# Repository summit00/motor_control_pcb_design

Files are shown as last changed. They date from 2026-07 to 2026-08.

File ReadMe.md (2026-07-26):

# STM32H563 BLDC Motor Controller

A three-phase BLDC/PMSM motor controller designed for high-performance Field-Oriented Control (FOC).

## Features

- STM32H563 microcontroller
- DRV8353 three-phase gate driver
- Three low-side current shunts
- Up to 60 V DC bus
- CAN interface
- USB-C interface
- Incremental encoder interface

## Repository Structure

```
.
├── motor_bldc_esc_V1.kicad_pro
├── motor_bldc_esc_V1.kicad_sch
├── motor_bldc_esc_V1.kicad_pcb
├── powerstage.kicad_sch
├── power.kicad_sch
├── mcu.kicad_sch
├── communication.kicad_sch
└── encoder.kicad_sch
```

## Status

🚧 Work in progress.

The hardware is currently under development and has not yet been validated on physical hardware.

## License

Hardware released under the CERN Open Hardware License.

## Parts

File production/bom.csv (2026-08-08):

Designator | Footprint | Quantity | Value | LCSC Part #
C1, C11, C12, C14, C16, C17, C18, C19, C20, C21, C22, C34, C4, C50 | 0603 | 14 | 100n | C14663
C10, C8, C9 | 0805 | 3 | 1u | C5370002
C13, C15 | 0603 | 2 | 33p | https://jlcpcb.com/partdetail/2015-CL10C330JB8NNNC/C1663
C2 | 1210 | 1 | 10u | C5156756
C23, C24, C25, C35, C49 | 0603 | 5 | 2u2 | C23630
C26, C27, C29, C38, C5 | 0805 | 5 | 100n | C28233
C28, C33, C43, C47 | 1210 | 4 | 4.7u | C381466
C3 | 0603 | 1 | 220p | C1603
C30, C44, C45, C46 | 0603 | 4 | 1u | C15849
C36, C39, C40, C41, C42 | 0805 | 5 | 10u | C15850
C37, C48 | 0603 | 2 | 2n2 | C1604
C6 | 0805 | 1 | 47n | C53134
C7 | 0805 | 1 | 1u | C28323
D4 | SOT-23 | 1 | PESD1CAN,215 | C15771
D5 | 0805 | 1 | LED_Status | C84256
D6 | 0805 | 1 | LED_Error | C84256
D7 | 0805 | 1 | LED_5V | C84256
D8 | 0805 | 1 | LED_3V3 | C84256
FB1 | 0805 | 1 | 60 | C845118
FB2 | 0603 | 1 | 120 | C14709
J6 | USB_C_Receptacle_G-Switch_GT-USB-7010ASV | 1 | USB_C_Receptacle_USB2.0_16P | C2988369
L1 | L_Sunlord_SWPA8040S | 1 | 39u | C206289
Q1, Q2, Q3, Q4, Q5, Q6 | TDSON-8-1 | 6 | BSC060N10NS3G | C501504
R1 | 0603 | 1 | 4k7 | C23162
R10 | 0805 | 1 | 200k | C17539
R11 | 0603 | 1 | 30k | C22984
R12 | 0805 | 1 | 100k | C149504
R13 | 0805 | 1 | 3k3 | C26010
R15 | 0603 | 1 | 47k | C25819
R16 | 0805 | 1 | 150 | C17471
R17, R30, R31 | 0603 | 3 | 330 | C23138
R18, R19 | 0603 | 2 | 5k1 | C23189
R2, R32, R33, R35 | 0805 | 4 | 10k | C17414
R20 | 0603 | 1 | 120 | C22787
R21 | 0603 | 1 | 68k | C23231
R22, R23, R24, R25, R26, R27 | 0603 | 6 | 2 | C22977
R28, R29 | 0603 | 2 | 100k | C25803
R34 | 0603 | 1 | 150k | C22807
R6, R7, R8 | 0805 | 3 | 120 | C17437
R9 | 0805 | 1 | 1M | C17514
U1 | DRV8353SRTAT | 1 | DRV8353SRTAT | C2150480
U3 | SOIC-16_3.9x9.9mm_P1.27mm | 1 | AM26LV32xD | C527448
U4 | SOT-23-5 | 1 | TLV75533PDBVR | C404027
U5 | LM5164DDAR | 1 | TI LM5164DDAR | C477928
U6 | SOT-23-6 | 1 | USBLC6-2SC6 | C7519
U7 | SOIC-8_3.9x4.9mm_P1.27mm | 1 | SN65HVD230DR | C12084
U8 | LQFP-100_14x14mm_P0.5mm | 1 | STM32H523VET6 | C27338462
Y1 | Crystal_SMD_5032-2Pin_5.0x3.2mm_HandSoldering | 1 | Crystal | C115962

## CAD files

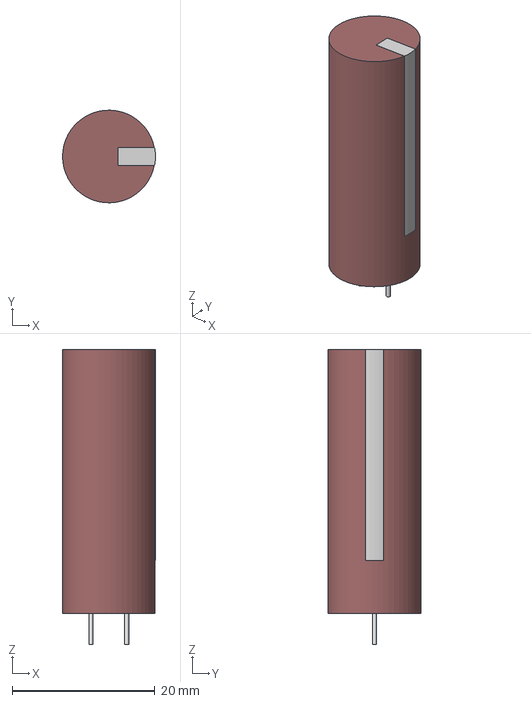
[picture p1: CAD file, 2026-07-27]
3dModels/100ZLJ330M12.5X35.step
13.0 x 13.0 x 41.4 mm

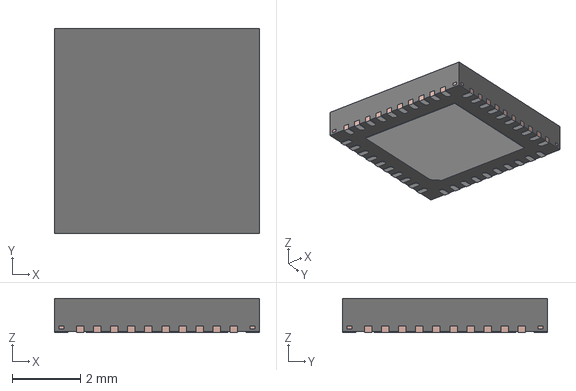
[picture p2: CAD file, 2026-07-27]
3dModels/DRV8353SRTAT.stp
6.00 x 6.00 x 1.00 mm
FRAME

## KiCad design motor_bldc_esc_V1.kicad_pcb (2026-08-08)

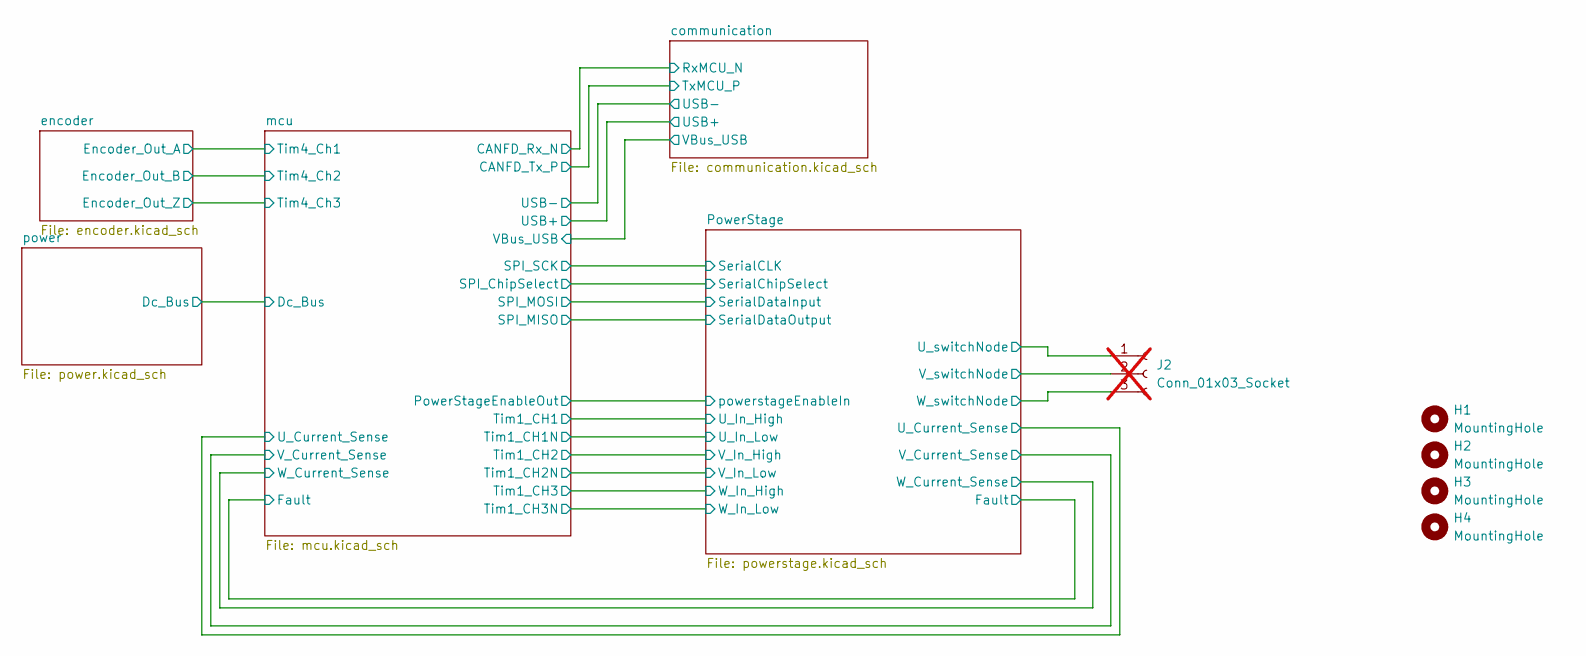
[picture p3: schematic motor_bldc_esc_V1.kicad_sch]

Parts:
H1, H2, H3, H4: MountingHole; MountingHole_3.2mm_M3
J2: Conn_01x03_Socket; SolderWire-4sqmm_1x03_P12mm_D3mm_OD6mm; not fitted

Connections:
/PowerStage/U_switchNode: J2.1; also elsewhere on the board
/PowerStage/V_switchNode: J2.2; also elsewhere on the board
/PowerStage/W_switchNode: J2.3; also elsewhere on the board

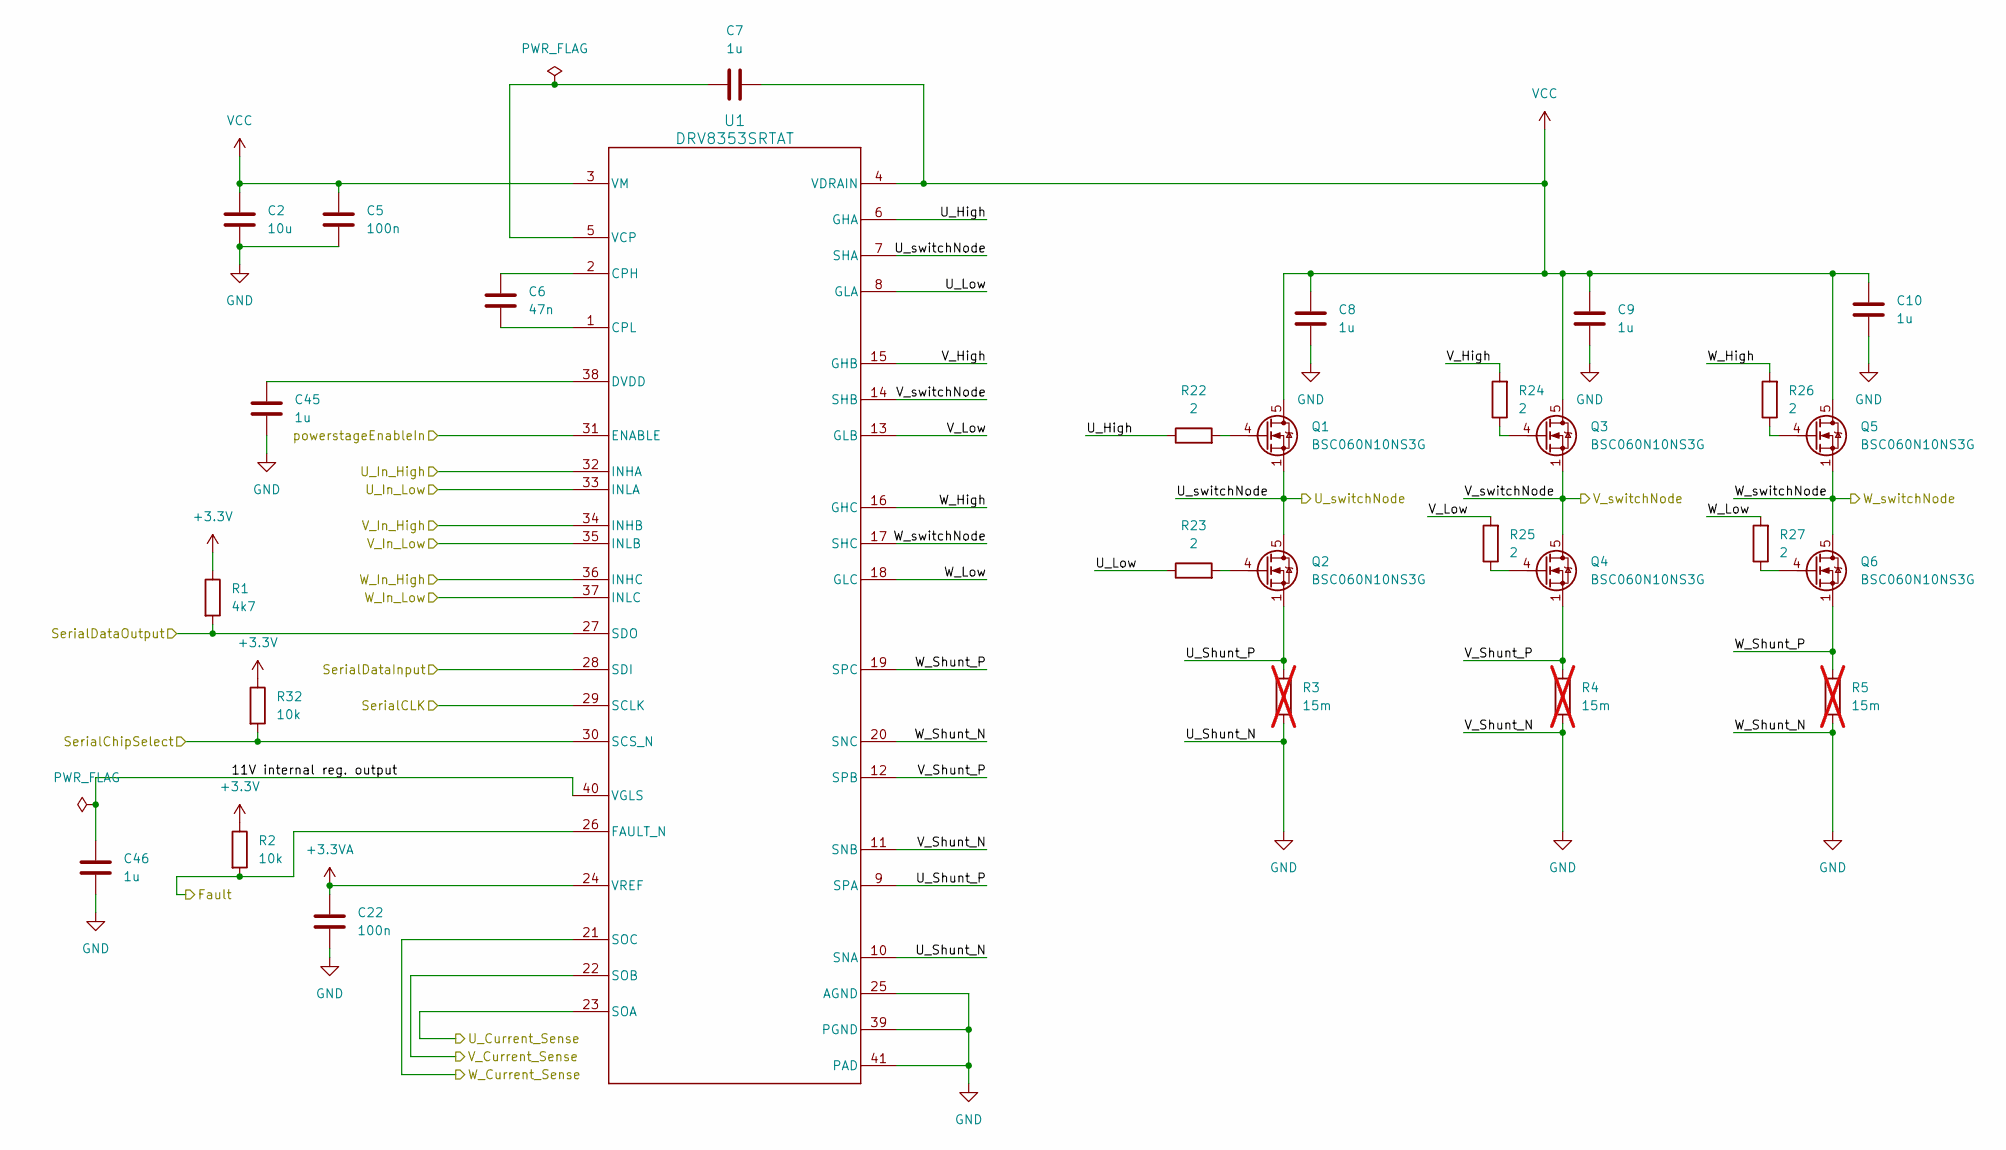
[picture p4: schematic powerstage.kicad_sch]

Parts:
C2: 10u; C_1210_3225Metric_Pad1.33x2.70mm_HandSolder; LCSC C5156756
C5: 100n; C_0805_2012Metric_Pad1.18x1.45mm_HandSolder; LCSC Part # C28233
C6: 47n; C_0805_2012Metric_Pad1.18x1.45mm_HandSolder; LCSC Part # C53134
C7: 1u; C_0805_2012Metric_Pad1.18x1.45mm_HandSolder; LCSC Part # C28323
C8, C9, C10: 1u; C_0805_2012Metric_Pad1.18x1.45mm_HandSolder; LCSC Part # C5370002
C22: 100n; C_0603_1608Metric; LCSC Part # C14663
C45, C46: 1u; C_0603_1608Metric; LCSC Part # C15849
Q1, Q2, Q3, Q4, Q5, Q6: BSC060N10NS3G; TDSON-8-1; LCSC Part # C501504
R1: 4k7; R_0603_1608Metric; LCSC Part # C23162
R2, R32: 10k; R_0805_2012Metric_Pad1.20x1.40mm_HandSolder; LCSC Part # C17414
R3, R4, R5: 15m; R_2512_6332Metric_Pad1.40x3.35mm_HandSolder; LCSC C7420045; not fitted
R22, R23, R24, R25, R26, R27: 2; R_0603_1608Metric; LCSC Part # C22977
U1: DRV8353SRTAT; LCSC Part # C2150480

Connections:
+3.3V: R1.1, R2.1, R32.1; also elsewhere on the board
+3.3VA: C22.1, U1.24 (VREF); also elsewhere on the board
/PowerStage/11V internal reg. output: C46.1, U1.40 (VGLS)
/PowerStage/Fault: R2.2, U1.26 (FAULT_N); also elsewhere on the board
/PowerStage/SerialCLK: U1.29 (SCLK); also elsewhere on the board
/PowerStage/SerialChipSelect: R32.2, U1.30 (SCS_N); also elsewhere on the board
/PowerStage/SerialDataInput: U1.28 (SDI); also elsewhere on the board
/PowerStage/SerialDataOutput: R1.2, U1.27 (SDO); also elsewhere on the board
/PowerStage/U_Current_Sense: U1.23 (SOA); also elsewhere on the board
/PowerStage/U_High: R22.1, U1.6 (GHA)
/PowerStage/U_In_High: U1.32 (INHA); also elsewhere on the board
/PowerStage/U_In_Low: U1.33 (INLA); also elsewhere on the board
/PowerStage/U_Low: R23.1, U1.8 (GLA)
/PowerStage/U_Shunt_P: Q2.1 (S), Q2.2 (S), Q2.3 (S), R3.1, U1.9 (SPA)
/PowerStage/U_switchNode: Q1.1 (S), Q1.2 (S), Q1.3 (S), Q2.5 (D), U1.7 (SHA); also elsewhere on the board
/PowerStage/V_Current_Sense: U1.22 (SOB); also elsewhere on the board
/PowerStage/V_High: R24.2, U1.15 (GHB)
/PowerStage/V_In_High: U1.34 (INHB); also elsewhere on the board
/PowerStage/V_In_Low: U1.35 (INLB); also elsewhere on the board
/PowerStage/V_Low: R25.2, U1.13 (GLB)
/PowerStage/V_Shunt_P: Q4.1 (S), Q4.2 (S), Q4.3 (S), R4.1, U1.12 (SPB)
/PowerStage/V_switchNode: Q3.1 (S), Q3.2 (S), Q3.3 (S), Q4.5 (D), U1.14 (SHB); also elsewhere on the board
/PowerStage/W_Current_Sense: U1.21 (SOC); also elsewhere on the board
/PowerStage/W_High: R26.2, U1.16 (GHC)
/PowerStage/W_In_High: U1.36 (INHC); also elsewhere on the board
/PowerStage/W_In_Low: U1.37 (INLC); also elsewhere on the board
/PowerStage/W_Low: R27.2, U1.18 (GLC)
/PowerStage/W_Shunt_P: Q6.1 (S), Q6.2 (S), Q6.3 (S), R5.1, U1.19 (SPC)
/PowerStage/W_switchNode: Q5.1 (S), Q5.2 (S), Q5.3 (S), Q6.5 (D), U1.17 (SHC); also elsewhere on the board
/PowerStage/powerstageEnableIn: U1.31 (ENABLE); also elsewhere on the board
GND: C2.2, C5.1, C8.2, C9.2, C10.2, C22.2, C45.2, C46.2, R3.2, R4.2, R5.2, U1.10 (SNA), U1.11 (SNB), U1.20 (SNC), U1.25 (AGND), U1.39 (PGND), U1.41 (PAD); also elsewhere on the board
unnamed: Q1.4 (G), R22.2
unnamed: Q2.4 (G), R23.2
unnamed: Q3.4 (G), R24.1
unnamed: Q4.4 (G), R25.1
unnamed: Q5.4 (G), R26.1
unnamed: Q6.4 (G), R27.1
unnamed: C6.2, U1.2 (CPH)
unnamed: C6.1, U1.1 (CPL)
unnamed: C45.1, U1.38 (DVDD)
unnamed: C7.1, U1.5 (VCP)
VCC: C2.1, C5.2, C7.2, C8.1, C9.1, C10.1, Q1.5 (D), Q3.5 (D), Q5.5 (D), U1.3 (VM), U1.4 (VDRAIN); also elsewhere on the board

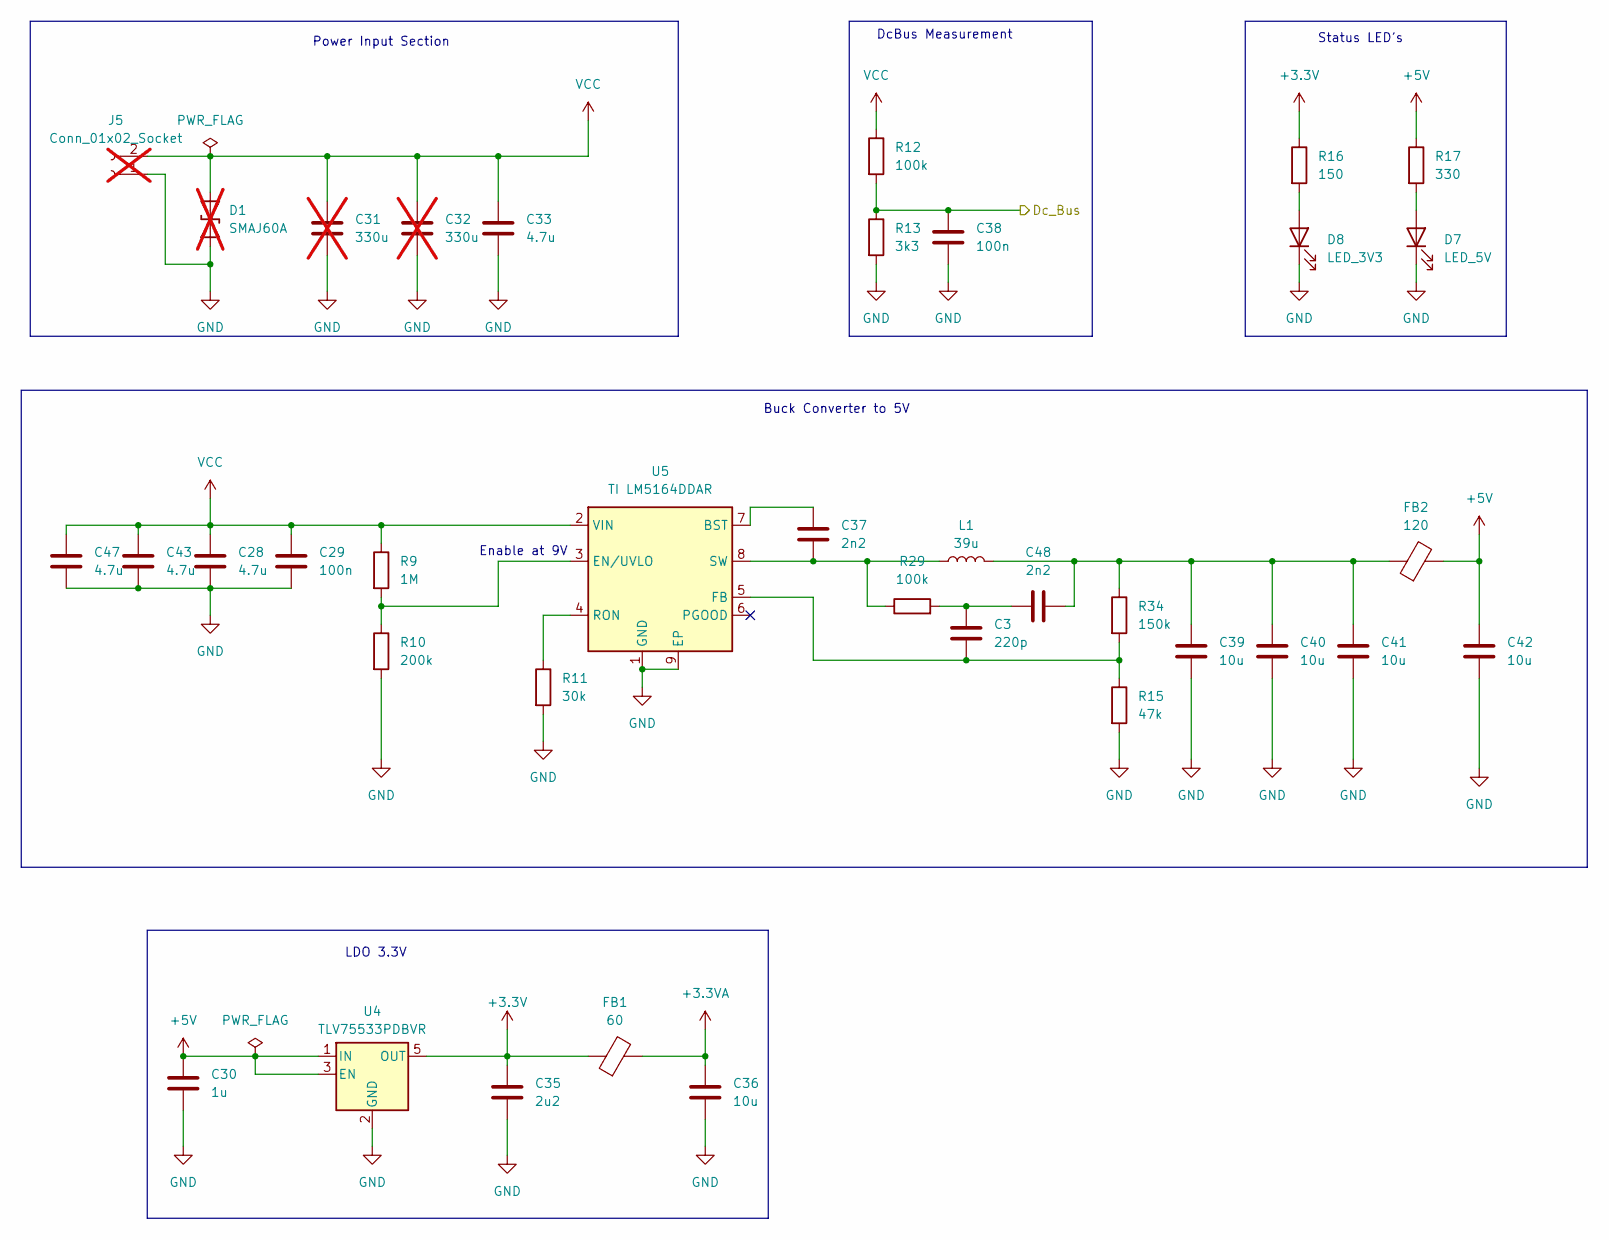
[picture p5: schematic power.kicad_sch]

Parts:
C3: 220p; C_0603_1608Metric; LCSC Part # C1603
C28, C33, C43, C47: 4.7u; C_1210_3225Metric_Pad1.33x2.70mm_HandSolder; LCSC C381466
C29, C38: 100n; C_0805_2012Metric_Pad1.18x1.45mm_HandSolder; LCSC Part # C28233
C30: 1u; C_0603_1608Metric; LCSC Part # C15849
C31, C32: 330u; 100ZLJ330M12.5X35; not fitted
C35: 2u2; C_0603_1608Metric; LCSC Part # C23630
C36, C39, C40, C41, C42: 10u; R_0805_2012Metric_Pad1.20x1.40mm_HandSolder; LCSC Part # C15850
C37, C48: 2n2; C_0603_1608Metric; LCSC Part # C1604
D1: SMAJ60A; D_SMA-SMB_Universal_Handsoldering; not fitted
D7: LED_5V; LED_0805_2012Metric; LCSC C84256
D8: LED_3V3; LED_0805_2012Metric; LCSC C84256
FB1: 60; L_0805_2012Metric_Pad1.05x1.20mm_HandSolder; LCSC Part # C845118
FB2: 120; L_0603_1608Metric_Pad1.05x0.95mm_HandSolder; LCSC Part # C14709
J5: Conn_01x02_Socket; SolderWire-4sqmm_1x02_P12mm_D3mm_OD6mm; not fitted
L1: 39u; L_Sunlord_SWPA8040S; LCSC Part # C206289
R9: 1M; R_0805_2012Metric; LCSC Part # C17514
R10: 200k; R_0805_2012Metric; LCSC Part # C17539
R11: 30k; R_0603_1608Metric; LCSC C22984
R12: 100k; R_0805_2012Metric_Pad1.20x1.40mm_HandSolder; LCSC Part # C149504
R13: 3k3; R_0805_2012Metric_Pad1.20x1.40mm_HandSolder; LCSC Part # C26010
R15: 47k; R_0603_1608Metric; LCSC Part # C25819
R16: 150; R_0805_2012Metric_Pad1.20x1.40mm_HandSolder; LCSC Part # C17471
R17: 330; R_0603_1608Metric; LCSC Part # C23138
R29: 100k; R_0603_1608Metric; LCSC Part # C25803
R34: 150k; R_0603_1608Metric; LCSC Part # C22807
U4: TLV75533PDBVR; SOT-23-5; LCSC Part # C404027
U5: TI LM5164DDAR; LM5164DDAR; LCSC Part # C477928

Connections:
+3.3V: C35.1, FB1.1, R16.1, U4.5 (OUT); also elsewhere on the board
+3.3VA: C36.1, FB1.2; also elsewhere on the board
+5V: C30.1, C42.1, FB2.2, R17.1, U4.1 (IN), U4.3 (EN); also elsewhere on the board
/mcu/Dc_Bus: C38.2, R12.2, R13.1; also elsewhere on the board
GND: C28.2, C29.1, C30.2, C31.2, C32.2, C33.2, C35.2, C36.2, C38.1, C39.2, C40.2, C41.2, C42.2, C43.2, C47.2, D1.1 (A1), D7.1 (K), D8.1 (K), J5.1, R10.2, R11.2, R13.2, R15.2, U4.2 (GND), U5.1 (GND), U5.9 (EP); also elsewhere on the board
unnamed: C3.1, C48.1, R29.2
unnamed: C39.1, C40.1, C41.1, C48.2, FB2.1, L1.2, R34.1
unnamed: D7.2 (A), R17.2
unnamed: D8.2 (A), R16.2
unnamed: C37.1, U5.7 (BST)
unnamed: R9.2, R10.1, U5.3 (EN/UVLO)
unnamed: C3.2, R15.1, R34.2, U5.5 (FB)
unnamed: R11.1, U5.4 (RON)
unnamed: C37.2, L1.1, R29.1, U5.8 (SW)
VCC: C28.1, C29.2, C31.1, C32.1, C33.1, C43.1, C47.1, D1.2 (A2), J5.2, R9.1, R12.1, U5.2 (VIN); also elsewhere on the board

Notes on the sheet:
Buck Converter to 5V
Enable at 9V
Power Input Section
LDO 3.3V
Status LED's
DcBus Measurement

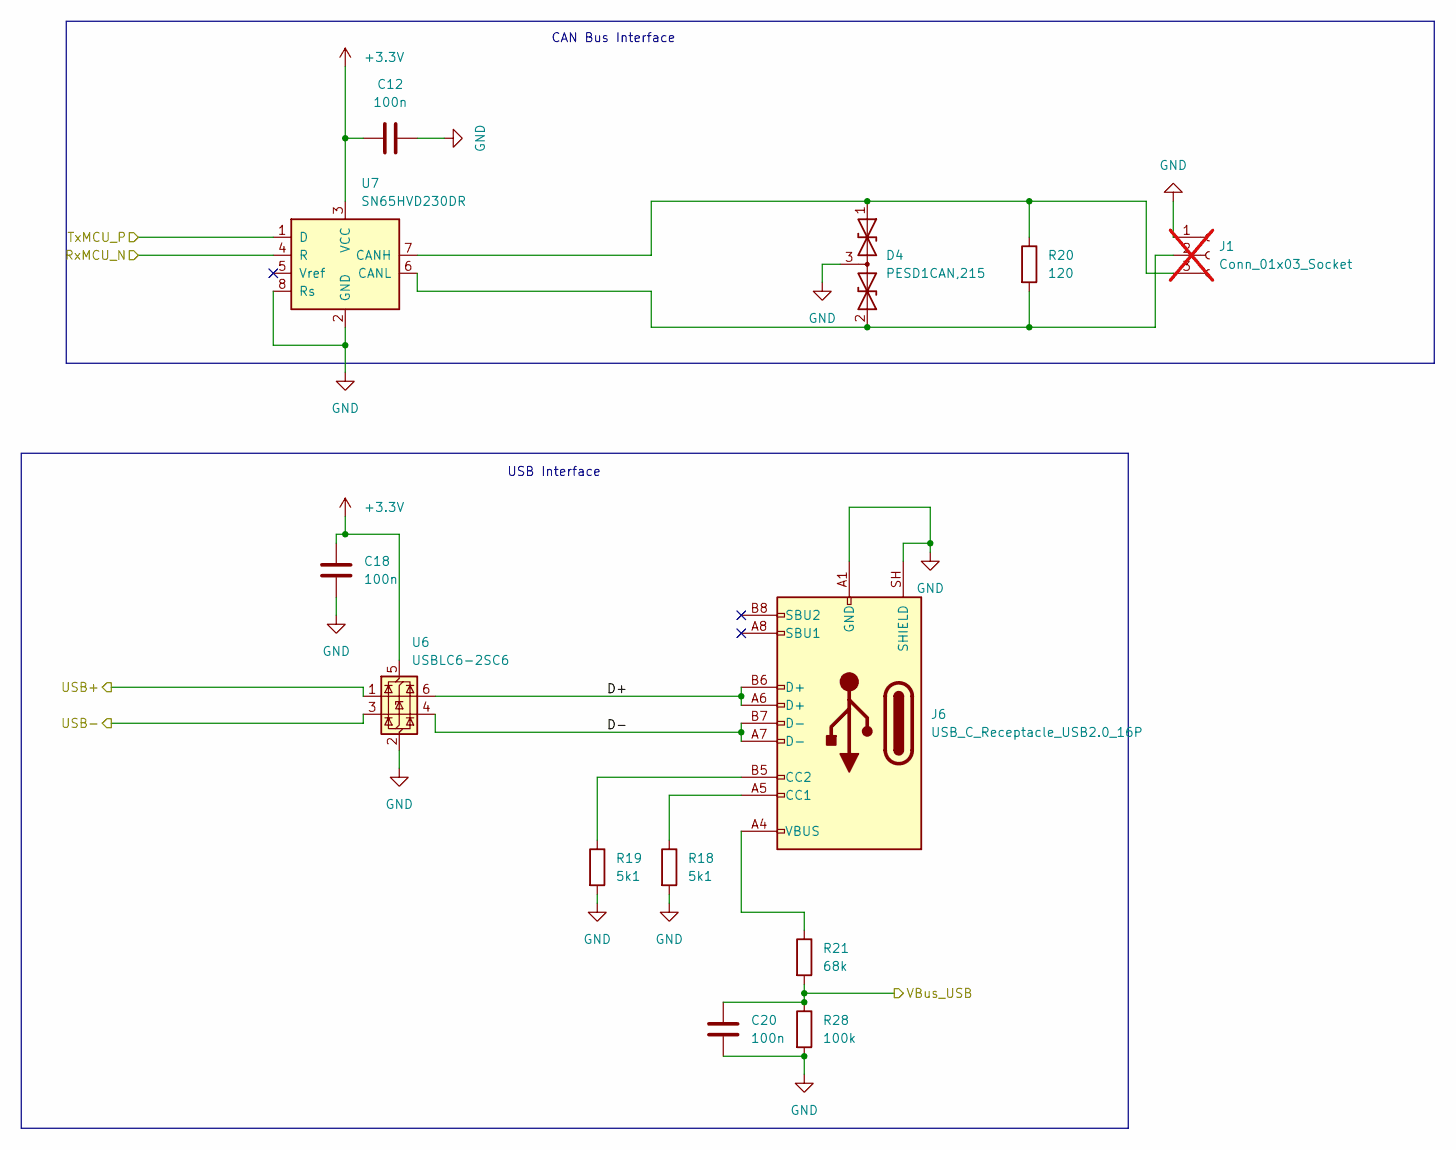
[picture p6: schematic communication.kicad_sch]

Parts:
C12, C18, C20: 100n; C_0603_1608Metric; LCSC Part # C14663
D4: PESD1CAN,215; SOT-23; LCSC Part # C15771
J1: Conn_01x03_Socket; JST_EH_B3B-EH-A_1x03_P2.50mm_Vertical; not fitted
J6: USB_C_Receptacle_USB2.0_16P; USB_C_Receptacle_G-Switch_GT-USB-7010ASV; LCSC Part # C2988369
R18, R19: 5k1; R_0603_1608Metric; LCSC Part # C23189
R20: 120; R_0603_1608Metric; LCSC Part # C22787
R21: 68k; R_0603_1608Metric; LCSC Part # C23231
R28: 100k; R_0603_1608Metric; LCSC Part # C25803
U6: USBLC6-2SC6; SOT-23-6; LCSC Part # C7519
U7: SN65HVD230DR; SOIC-8_3.9x4.9mm_P1.27mm; LCSC Part # C12084

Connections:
+3.3V: C12.1, C18.1, U6.5 (VBUS), U7.3 (VCC); also elsewhere on the board
/communication/D+: J6.A6 (D+), J6.B6 (D+), U6.6 (I/O1)
/communication/D-: J6.A7 (D-), J6.B7 (D-), U6.4 (I/O2)
/communication/RxMCU_N: U7.4 (R); also elsewhere on the board
/communication/TxMCU_P: U7.1 (D); also elsewhere on the board
/communication/USB+: U6.1 (I/O1); also elsewhere on the board
/communication/USB-: U6.3 (I/O2); also elsewhere on the board
/communication/VBus_USB: C20.1, R21.2, R28.1; also elsewhere on the board
GND: C12.2, C18.2, C20.2, D4.3 (common), J1.1, J6.A1 (GND), J6.A12 (GND), J6.B1 (GND), J6.B12 (GND), J6.SH (SHIELD), R18.2, R19.2, R28.2, U6.2 (GND), U7.2 (GND), U7.8 (Rs); also elsewhere on the board
unnamed: D4.1 (A1), J1.3, R20.1, U7.7 (CANH)
unnamed: D4.2 (A2), J1.2, R20.2, U7.6 (CANL)
unnamed: J6.A5 (CC1), R18.1
unnamed: J6.B5 (CC2), R19.1
unnamed: J6.A4 (VBUS), J6.A9 (VBUS), J6.B4 (VBUS), J6.B9 (VBUS), R21.1

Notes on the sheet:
CAN Bus Interface
USB Interface

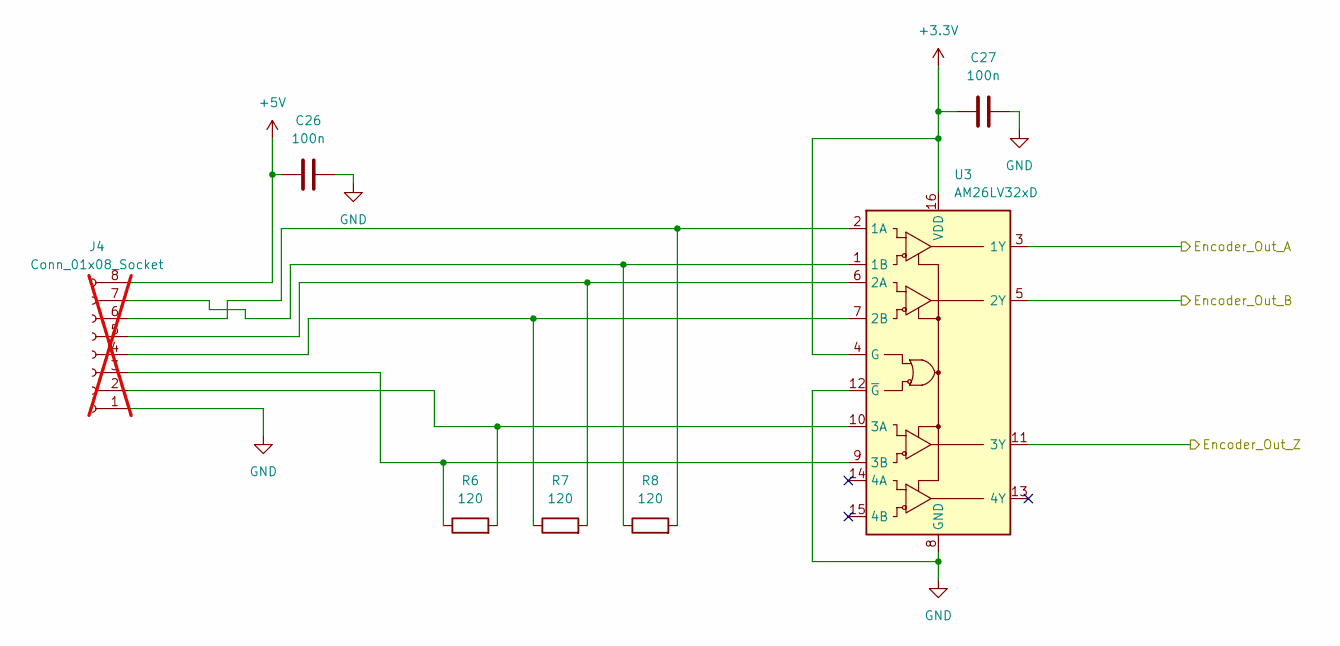
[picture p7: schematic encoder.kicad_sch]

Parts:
C26, C27: 100n; C_0805_2012Metric_Pad1.18x1.45mm_HandSolder; LCSC Part # C28233
J4: Conn_01x08_Socket; JST_XH_B8B-XH-A_1x08_P2.50mm_Vertical; not fitted
R6, R7, R8: 120; R_0805_2012Metric_Pad1.20x1.40mm_HandSolder; LCSC Part # C17437
U3: AM26LV32xD; SOIC-16_3.9x9.9mm_P1.27mm; LCSC Part # C527448

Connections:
+3.3V: C27.2, U3.4 (G), U3.16 (VDD); also elsewhere on the board
+5V: C26.2, J4.8; also elsewhere on the board
/encoder/Encoder_Out_A: U3.3 (1Y); also elsewhere on the board
/encoder/Encoder_Out_B: U3.5 (2Y); also elsewhere on the board
/encoder/Encoder_Out_Z: U3.11 (3Y); also elsewhere on the board
GND: C26.1, C27.1, J4.1, U3.8 (GND), U3.12 (~G); also elsewhere on the board
unnamed: J4.2, R6.2, U3.10 (3A)
unnamed: J4.3, R6.1, U3.9 (3B)
unnamed: J4.4, R7.1, U3.7 (2B)
unnamed: J4.5, R7.2, U3.6 (2A)
unnamed: J4.6, R8.2, U3.2 (1A)
unnamed: J4.7, R8.1, U3.1 (1B)

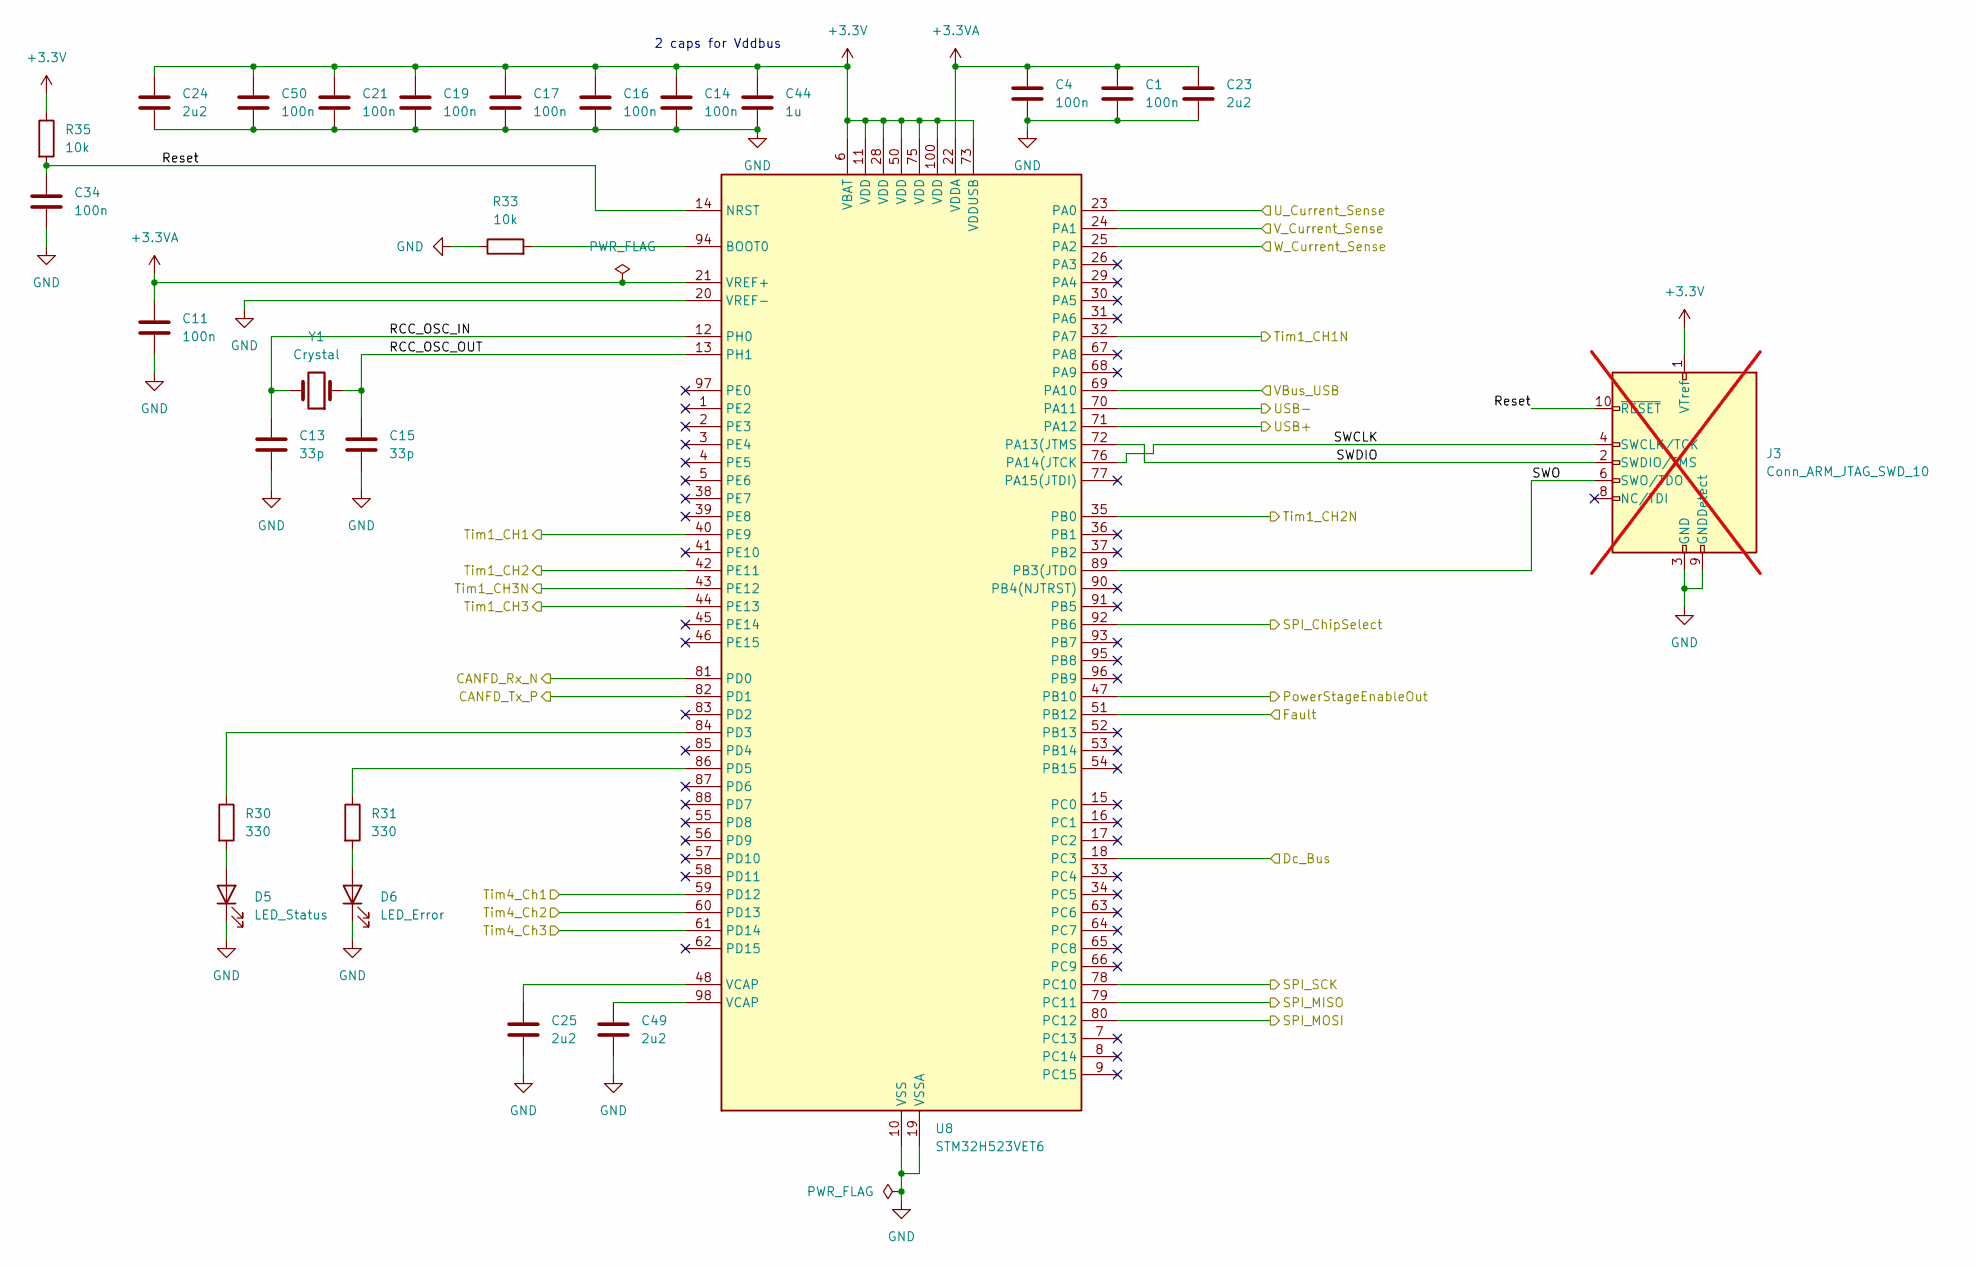
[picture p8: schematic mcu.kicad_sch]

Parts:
C1, C4, C11, C14, C16, C17, C19, C21, C34, C50: 100n; C_0603_1608Metric; LCSC Part # C14663
C13, C15: 33p; C_0603_1608Metric
C23, C24, C25, C49: 2u2; C_0603_1608Metric; LCSC Part # C23630
C44: 1u; C_0603_1608Metric; LCSC Part # C15849
D5: LED_Status; LED_0805_2012Metric; LCSC C84256
D6: LED_Error; LED_0805_2012Metric; LCSC C84256
J3: Conn_ARM_JTAG_SWD_10; PinHeader_2x05_P1.27mm_Vertical; not fitted
R30, R31: 330; R_0603_1608Metric; LCSC Part # C23138
R33, R35: 10k; R_0805_2012Metric_Pad1.20x1.40mm_HandSolder; LCSC Part # C17414
U8: STM32H523VET6; LQFP-100_14x14mm_P0.5mm; LCSC Part # C27338462
Y1: Crystal; Crystal_SMD_5032-2Pin_5.0x3.2mm_HandSoldering; LCSC Part # C115962

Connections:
+3.3V: C14.1, C16.1, C17.1, C19.1, C21.1, C24.1, C44.1, C50.1, J3.1 (VTref), R35.1, U8.6 (VBAT), U8.11 (VDD), U8.28 (VDD), U8.50 (VDD), U8.73 (VDDUSB), U8.75 (VDD), U8.100 (VDD); also elsewhere on the board
+3.3VA: C1.1, C4.1, C11.1, C23.1, U8.21 (VREF+), U8.22 (VDDA); also elsewhere on the board
/PowerStage/Fault: U8.51 (PB12); also elsewhere on the board
/PowerStage/SerialCLK: U8.78 (PC10); also elsewhere on the board
/PowerStage/SerialChipSelect: U8.92 (PB6); also elsewhere on the board
/PowerStage/SerialDataInput: U8.80 (PC12); also elsewhere on the board
/PowerStage/SerialDataOutput: U8.79 (PC11); also elsewhere on the board
/PowerStage/U_Current_Sense: U8.23 (PA0); also elsewhere on the board
/PowerStage/U_In_High: U8.40 (PE9); also elsewhere on the board
/PowerStage/U_In_Low: U8.32 (PA7); also elsewhere on the board
/PowerStage/V_Current_Sense: U8.24 (PA1); also elsewhere on the board
/PowerStage/V_In_High: U8.42 (PE11); also elsewhere on the board
/PowerStage/V_In_Low: U8.35 (PB0); also elsewhere on the board
/PowerStage/W_Current_Sense: U8.25 (PA2); also elsewhere on the board
/PowerStage/W_In_High: U8.44 (PE13); also elsewhere on the board
/PowerStage/W_In_Low: U8.43 (PE12); also elsewhere on the board
/PowerStage/powerstageEnableIn: U8.47 (PB10); also elsewhere on the board
/communication/RxMCU_N: U8.81 (PD0); also elsewhere on the board
/communication/TxMCU_P: U8.82 (PD1); also elsewhere on the board
/communication/USB+: U8.71 (PA12); also elsewhere on the board
/communication/USB-: U8.70 (PA11); also elsewhere on the board
/communication/VBus_USB: U8.69 (PA10); also elsewhere on the board
/encoder/Encoder_Out_A: U8.59 (PD12); also elsewhere on the board
/encoder/Encoder_Out_B: U8.60 (PD13); also elsewhere on the board
/encoder/Encoder_Out_Z: U8.61 (PD14); also elsewhere on the board
/mcu/Dc_Bus: U8.18 (PC3); also elsewhere on the board
/mcu/RCC_OSC_IN: C13.1, U8.12 (PH0), Y1.2
/mcu/RCC_OSC_OUT: C15.1, U8.13 (PH1), Y1.1
/mcu/Reset: C34.1, J3.10 (~RESET), R35.2, U8.14 (NRST)
/mcu/SWCLK: J3.4 (SWCLK/TCK), U8.76 (PA14(JTCK)
/mcu/SWDIO: J3.2 (SWDIO/TMS), U8.72 (PA13(JTMS)
/mcu/SWO: J3.6 (SWO/TDO), U8.89 (PB3(JTDO)
GND: C1.2, C4.2, C11.2, C13.2, C14.2, C15.2, C16.2, C17.2, C19.2, C21.2, C23.2, C24.2, C25.2, C34.2, C44.2, C49.2, C50.2, D5.1 (K), D6.1 (K), J3.3 (GND), J3.5 (GND), J3.9 (GNDDetect), R33.1, U8.10 (VSS), U8.19 (VSSA), U8.20 (VREF-), U8.27 (VSS), U8.49 (VSS), U8.74 (VSS), U8.99 (VSS); also elsewhere on the board
unnamed: C25.1, U8.48 (VCAP)
unnamed: C49.1, U8.98 (VCAP)
unnamed: D5.2 (A), R30.2
unnamed: D6.2 (A), R31.2
unnamed: R33.2, U8.94 (BOOT0)
unnamed: R30.1, U8.84 (PD3)
unnamed: R31.1, U8.86 (PD5)

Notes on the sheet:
2 caps for Vddbus

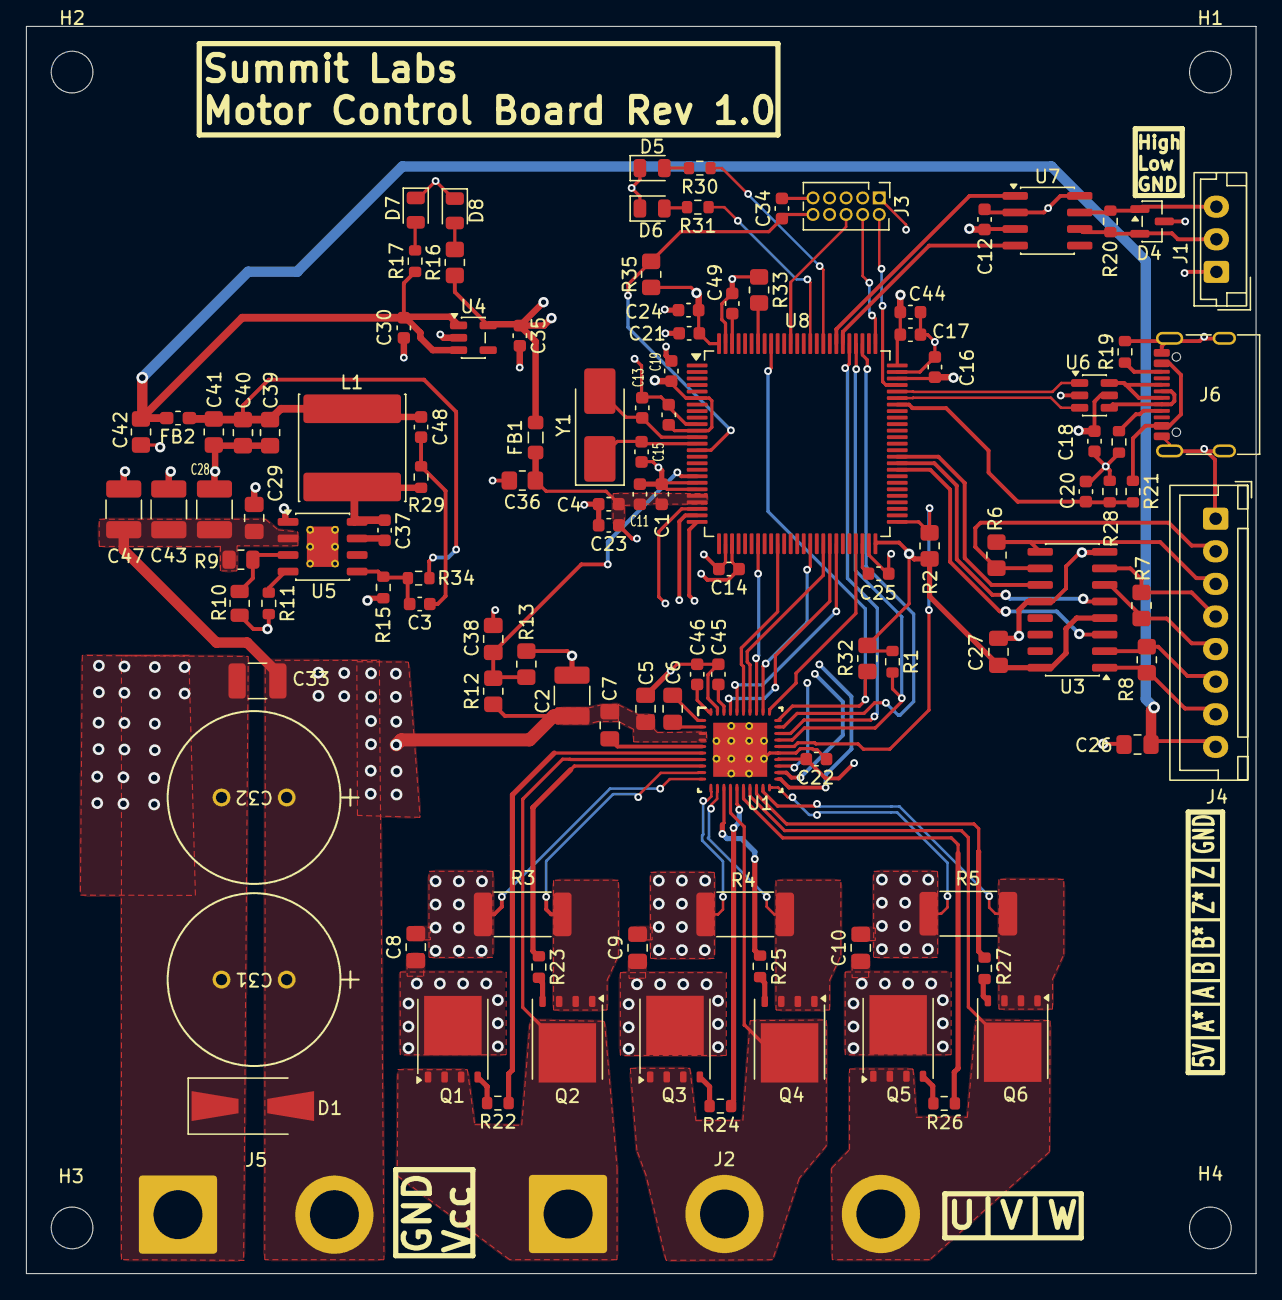
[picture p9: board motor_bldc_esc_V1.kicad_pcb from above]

Board: 4 copper layers, 94.3 x 95.7 mm, 117 parts (0 on the bottom side), 87 nets.

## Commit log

2026-07-27 edit symbols because of DRC errors (DRV and LM5164)
    [100ZLJ330M12.5X35.step, DRV8353SRTAT.stp, bom.csv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]
2026-07-30 update pcb (no errors with XRC)
    [bom.csv, mcu.kicad_sch, motor_bldc_esc_V1.kicad_pcb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]
2026-08-01 finished design of PCB
    [mcu.kicad_sch, motor_bldc_esc_V1.kicad_pcb, motor_bldc_esc_V1.kicad_sch]
2026-08-08 changes MCU because of stock
    [bom.csv, designators.csv, mcu.kicad_sch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]
